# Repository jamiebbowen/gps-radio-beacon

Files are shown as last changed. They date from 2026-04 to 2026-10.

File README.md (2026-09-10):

# GPS Radio Beacon

A long-range rocket-tracking system: an airborne **transmitter** continuously
reports GPS position over LoRa, and a handheld **receiver** displays bearing,
distance, and altitude to help recover the rocket after landing.

Tested on a Mach-0.99 / 2 km AGL flight with a 37 dB link margin — see
[`docs/flight-analysis.md`](docs/flight-analysis.md) for post-flight tooling.

## System overview

```
+-------------------------+           LoRa 433 MHz          +-------------------------+
|       TRANSMITTER       |  - - - - - - - - - - - - - ->  |         RECEIVER        |
|  (flies with the rocket)|   ~15+ km LoS (SF10/62.5kHz)  |   (handheld ground)     |
+-------------------------+                                 +-------------------------+
  - ItsyBitsy M4 (SAMD51)                                     - STM32F401 Black Pill
  - u-blox GPS (UART)                                         - NEO-6M GPS (UART)
  - BNO085 IMU (I2C) - launch detect                          - BNO055 IMU (I2C) - compass
  - E22-400M33S LoRa (SPI)                                    - E22 LoRa (SPI)
  - Power: 3.3 V + LiPo                                       - SSD1309 OLED (I2C)
                                                              - microSD log (SPI, littlefs)
```

The transmitter runs a state machine (`PRE_LAUNCH` -> `LAUNCH` -> `POST_LAUNCH`
-> `BATTERY_SAVE`) that auto-adapts TX cadence based on IMU-detected liftoff.
The receiver logs every packet to SD card for post-flight analysis.

## Repository layout

```
.
|-- transmitter/
|   |-- firmware/            Arduino/C++ code for the ItsyBitsy M4
|   |                        (radio, GPS, IMU, beacon state machine)
|   `-- pcb/                 KiCad schematic + PCB design
|
|-- receiver/
|   |-- firmware/            Bare-metal STM32 HAL code
|   |                        (radio, GPS, compass, OLED, SD card, navigation UI)
|   `-- tools/
|       `-- analyze_flight.py  Post-flight log analyzer + KML/MP4 renderer
|
|-- tools/
|   |-- log_summary.py       Field-log health forensics (wedges, watchdogs,
|   |                          telemetry gaps) - run on a session directory
|   `-- lfs_extract/         Pull Lxxxxxxx.TXT logs off the littlefs SD image
|
|-- docs/                    Reference documentation (wiring, radio config,
|                            reliability, troubleshooting)
|   `-- archive/             Historical bug post-mortems and migration notes
|
`-- README.md                This file
```

## Quick start

### Transmitter (ItsyBitsy M4)

```bash
cd transmitter/firmware
make install-deps     # one-time: installs arduino-cli + Adafruit SAMD core
make compile
make flash            # flashes via /dev/ttyACM0 by default
make monitor          # optional: USB serial log
```

Edit `include/mpu_config.h` to set your amateur-radio callsign.

### Receiver (STM32F401)

```bash
cd receiver/firmware
make                  # builds bin/gps_radio_beacon_receiver.elf
# Flash with st-flash, OpenOCD, or DFU as appropriate for your toolchain
```

### Flight analysis

After a flight, pull the SD card from the receiver and extract the logs
(the card is littlefs, not FAT):

```bash
make extract DEV=/dev/sdX                        # -> flight_data/<timestamp>/
python3 tools/log_summary.py flight_data/<ts>/   # health audit in seconds
python3 receiver/tools/analyze_flight.py flight_data/<ts>/L0001.TXT
```

Options:

| Flag | Purpose |
|---|---|
| `--kml flight.kml` | Google-Earth replay with time-animated rocket track |
| `--mp4 flight.mp4` | Headless 3-D animated replay (matplotlib + ffmpeg) |
| `--duration 15` | Compress flight into N-second video |
| `--sensitivity -134` | Override receiver sensitivity for range prediction |

Prints altitude, velocity, slant range, RSSI/SNR trace, predicted max range,
and packet-continuity statistics. See
[`docs/flight-analysis.md`](docs/flight-analysis.md) for details.

## Documentation

Detailed reference docs live in [`docs/`](docs/):

- **Hardware wiring**: receiver and transmitter pin assignments
- **LoRa radio**: E22-400M33S configuration and link-budget notes
- **Launch detection**: BNO085 IMU threshold tuning
- **GPS watchdog**: automatic recovery from fix loss
- **Reliability**: signal-quality monitoring, staleness, validation
- **SD card troubleshooting**: diagnostics for the receiver logger
- **Flight analysis**: using `analyze_flight.py`

Post-mortems of specific bug fixes are preserved under
[`docs/archive/`](docs/archive/).

## License / legal

The LoRa link operates on the 433 MHz band. In the US this falls under the
amateur-radio 70 cm allocation; the beacon transmits its callsign every
few minutes for FCC compliance. **Check your local regulations and hold
an appropriate license before transmitting.**

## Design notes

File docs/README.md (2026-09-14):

# Documentation index

Reference docs for the GPS radio beacon. Each file is self-contained; links
between them are cross-referenced where relevant.

## Hardware / wiring

- [`hardware-receiver.md`](hardware-receiver.md) - STM32F401 Black Pill pin
  assignments, peripherals, power, and connector layout.
- [`hardware-transmitter.md`](hardware-transmitter.md) - ItsyBitsy M4 Express
  pin assignments for GPS, LoRa, IMU, and power.
- [`pin-comparison.md`](pin-comparison.md) - Side-by-side TX vs RX pin-map
  quick reference.

## Radio / RF

- [`lora-radio.md`](lora-radio.md) - E22-400M33S module configuration and
  the software conversion from the original simple 433 MHz modules.
- [`reliability.md`](reliability.md) - Consolidated reliability doc:
  transmitter data validation, receiver signal-quality monitoring, LoRa
  link budget, and regulatory notes.

## Sensors / subsystems

- [`launch-detection.md`](launch-detection.md) - BNO085 IMU-based launch
  detection: threshold, debounce, and tuning guidance.
- [`gps-watchdog.md`](gps-watchdog.md) - Automatic GPS recovery system for
  silent fix loss.

## Operations / troubleshooting

- [`launch-day.md`](launch-day.md) - Field runbook: pad workflow, flight,
  recovery walk, crowded channels, and post-flight log review.
- [`bench-checklist.md`](bench-checklist.md) - Hardware power-up checks
  after flashing and before launch weekends.
- [`sd-card-troubleshooting.md`](sd-card-troubleshooting.md) - Diagnostics
  for the receiver SD-card logger.
- [`flight-analysis.md`](flight-analysis.md) - Using
  `receiver/tools/analyze_flight.py` for post-flight stats, KML replay,
  and MP4 rendering.

## Archive

[`archive/`](archive/) holds historical material that is no longer part of
the "current truth" but is worth preserving for context:

- Bug post-mortems (`clock-analysis`, `magic-number-solution`, `sd-cmd0-fix`,
  `lora-timing-fix`, `pin-changes-summary`)
- Design history (`binary-packet-proposal` - since **adopted**; the current
  wire format is the binary typed packets described in
  `transmitter/firmware/include/rf_packet.h`)
- Documents superseded by the main README or by a consolidated doc in this
  folder (`complete-system-summary`, `migration-guide`, `port-summary`,
  `build-fix`, `upload-fix`, `e22-400m33s-wiring`)

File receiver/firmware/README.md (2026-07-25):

# GPS Radio Beacon Receiver Firmware

This firmware is designed for an STM32F401 microcontroller-based receiver that tracks the location of a transmitter using GPS coordinates.

## Hardware Components
- STM32F401 Microcontroller
- QMX588L Compass Module
- NEO6M GPS Module
- RXM-433-LR RF Receiver
- SSD1309 OLED Display

## Functionality
The system receives GPS coordinates from a remote transmitter via the RF receiver, compares them with the local GPS position, and uses the compass to determine the relative direction and distance to the transmitter. The information is displayed on the OLED screen.

## Display Information
- Direction (degrees off from straight ahead)
- Distance to transmitter (meters)
- Time since last received ping

## Project Structure
- `inc/` - Header files
- `src/` - Source files
- `lib/` - Vendored libraries (littlefs is tracked; STM32CubeF4 is not - see below)
- `Makefile` - Build configuration

## Building

Requires `arm-none-eabi-gcc` and a local copy of STM32CubeF4, which is too
large (1+ GB) to track in this repository. On a fresh clone, fetch it once:

```bash
git clone --depth 1 --branch v1.28.2 \
    https://github.com/STMicroelectronics/STM32CubeF4.git lib/STM32CubeF4
cd lib/STM32CubeF4
git submodule update --init --depth 1 \
    Drivers/STM32F4xx_HAL_Driver \
    Drivers/CMSIS/Device/ST/STM32F4xx
```

Then build with:

```bash
make
```

Output artifacts land in `bin/` (`.elf`, `.bin`, `.hex`). CI performs the
same steps (see `.github/workflows/ci.yml`).

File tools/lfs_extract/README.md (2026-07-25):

# `lfs_extract` — pull flight data off the LittleFS SD card

The receiver writes `L####.TXT`, `BEACON.TXT`, and `COMPCAL.BIN` to the SD
card using **LittleFS**, not FAT. That choice gives us real power-fail
safety (the card can never be corrupted by a mid-write reset), but it means
Linux / macOS / Windows can no longer mount the card directly.

`lfs_extract` solves the read-back side: it opens the card as a raw block
device, mounts the LittleFS image in user-space, and copies every file out
to a normal host directory.

## Build

```sh
make -C tools/lfs_extract
```

Produces a single binary, `tools/lfs_extract/lfs_extract`.

## Use

```sh
# Identify the SD card device with `lsblk` or `dmesg | tail` first.
sudo tools/lfs_extract/lfs_extract /dev/sdb ./flight_data_2026_04_20
```

Root (or `disk` group membership) is required because the tool reads the
raw block device, not a mounted filesystem.

Typical output:

```
Device: /dev/sdb
Size:   29.72 GiB (7789184 LFS blocks)

Extracting:
  /BEACON.TXT                   30 bytes
  /COMPCAL.BIN                  25 bytes
  /L0001.TXT                14623 bytes
  /L0002.TXT               912442 bytes

Summary:
  files copied : 4
  bytes copied : 927120
  card used    : 342 / 7789184 blocks (0.00 %)
  output dir   : ./flight_data_2026_04_20
```

## Related top-level targets

From the repo root:

```sh
# Build this tool:
make tools

# One-shot extract:
make extract DEV=/dev/sdb OUT=./flight_data

# Wipe and re-format the card to LittleFS on the host (skips the firmware
# auto-format path, useful when re-using a card between flights):
make format-card DEV=/dev/sdb
```

## Constraint: geometry must match the firmware

The on-card layout is defined in `receiver/firmware/src/lfs_sd_bd.c`:

| Parameter | Value  |
|---|---|
| Sector size | 512 B  |
| Block size  | 4096 B |
| Cache size  | 512 B  |
| Lookahead | 128 B  |

`lfs_extract.c` mirrors these constants. If you ever tune them on the
firmware side, update this file to match (and reformat existing cards).

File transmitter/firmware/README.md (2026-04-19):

# GPS Radio Beacon - ItsyBitsy M4 Express Port

Successfully ported from ATtiny412 to **Adafruit ItsyBitsy M4 Express** (SAMD51 ARM Cortex-M4 @ 120MHz)

## Hardware Configuration

### Pin Assignments
- **Pin 11**: Radio TX (bit-banged UART at 300 baud)
- **Pin 12**: Radio Enable/Disable
- **Pin 10**: Launch Detection Switch (active low with pull-up)
- **Pins 0/1**: GPS UART (Hardware Serial1, 115200 baud)

### Connections
```
ItsyBitsy M4          Component
-----------           ---------
Pin 11         --->   Radio TX Data In
Pin 12         --->   Radio Enable/PTT
Pin 10         --->   Launch Switch (to GND when launched)
Pin 0 (RX1)    <---   GPS TX
Pin 1 (TX1)    --->   GPS RX
GND            --->   Common Ground
USB/5V         --->   Power Input
```

## Software Architecture

### Arduino Framework
The firmware now uses the Arduino framework instead of bare-metal AVR:
- **Hardware Serial1**: GPS communication (no more bit-banging)
- **Arduino timing**: `millis()`, `delay()`, `delayMicroseconds()`
- **GPIO**: `pinMode()`, `digitalWrite()`, `digitalRead()`
- **No watchdog**: SAMD51 doesn't enable watchdog by default

### Build System
Uses `arduino-cli` for command-line compilation and upload:
- No Arduino IDE required
- Makefile-based workflow
- Cross-platform support

## Installation

### 1. Install Arduino CLI

```bash
# Linux/macOS
curl -fsSL https://raw.githubusercontent.com/arduino/arduino-cli/master/install.sh | sh
sudo mv bin/arduino-cli /usr/local/bin/

# Or download from: https://arduino.github.io/arduino-cli/
```

### 2. Install Board Support

```bash
make install-deps
```

This installs Adafruit SAMD board support package.

### 3. Connect ItsyBitsy M4

Plug in the ItsyBitsy M4 via USB. It should appear as `/dev/ttyACM0` (Linux) or similar.

## Building and Uploading

### Compile Only
```bash
make compile
```

### Upload to Board
```bash
make flash
# Or specify port:
make PORT=/dev/ttyACM1 flash
```

### Monitor Serial Output
```bash
make monitor
```

### Clean Build
```bash
make clean
```

## Configuration

### Callsign
Edit `include/mpu_config.h` (yes, kept the filename for compatibility):
```c
#define BEACON_CALLSIGN "KD0ABC"  // Change to your callsign
```

### Timing Modes
Edit `include/config.h`:
```c
#define TESTING_MODE 0  // 0 = production, 1 = testing
```

**Testing Mode** (fast intervals for bench testing):
- Pre-launch: 10s intervals
- Launch: continuous for 30s
- Post-launch: continuous for 30s
- Battery save: 30s intervals
- Callsign: every 30s

**Production Mode** (optimized for flight):
- Pre-launch: 30s intervals
- Launch: continuous for 5 minutes
- Post-launch: continuous for 10 minutes  
- Battery save: 60s intervals
- Callsign: every 5 minutes

## Packet Format

### GPS Data Packet
```
$$lat,lon,alt,sats$$CHKSUM
```
Example: `$$3953.40363,-10506.93605,1671.7,12$$2F`

- Coordinates in NMEA format (DDMM.MMMMM)
- Negative sign for South/West
- XOR checksum in hex
- 300 baud transmission

### Fast GPS Packet (during launch)
```
$$lat,lon,alt$$CHKSUM
```
Omits satellite count for faster transmission.

### Callsign Packet
```
KD0ABC
```
Transmitted every 5 minutes for FCC compliance.

## Advantages Over ATtiny412

### Performance
- **480x faster CPU**: 120MHz vs 20MHz
- **768x more RAM**: 192KB vs 256 bytes
- **98x more Flash**: 512KB vs 4KB
- **Hardware UART**: No bit-banging for GPS

### Features
- USB Serial for debugging (`Serial.begin(115200)`)
- Hardware floating-point unit
- DMA support (not used yet)
- Real-time clock (not used yet)
- No memory constraints - can add features easily

### Development
- Easier debugging via USB Serial
- Faster compile times
- Arduino ecosystem libraries available
- No fuse programming required

## Beacon State Machine

1. **PRE_LAUNCH**: Waiting on pad, 30s intervals
2. **LAUNCH**: Continuous transmission for 5 min (180s fast, then full)
3. **POST_LAUNCH**: Continuous transmission for next 10 min
4. **BATTERY_SAVE**: 60s intervals indefinitely

Launch detection triggers from ANY state.

## Troubleshooting

### Board Not Found
```bash
# List connected boards
arduino-cli board list

# Try different port
make PORT=/dev/ttyACM1 flash
```

### Compilation Errors
```bash
# Reinstall board support
arduino-cli core update-index
arduino-cli core install adafruit:samd
```

### GPS Not Working
- Check Serial1 connections (pins 0/1)
- GPS expects 115200 baud, 3.3V logic
- ItsyBitsy M4 is 3.3V compatible

### Radio Not Transmitting
- Check pin 11 for TX data (300 baud)
- Check pin 12 for enable signal
- Verify radio module power

## Development Notes

### File Structure
- `main.cpp`: Main program with state machine
- `gps.cpp`: GPS parsing (NMEA)
- `radio.cpp`: Bit-banged 300 baud UART
- `uart.cpp`: Hardware Serial wrapper
- `beacon.cpp`: Packet formatting
- `launch_detect.cpp`: Launch switch debouncing
- `include/`: Headers
- `gps_radio_beacon.ino`: Arduino sketch wrapper

### Adding Features
With 192KB RAM and 512KB Flash, you can easily add:
- SD card logging
- Additional sensors (accelerometer, barometer)
- Data buffering
- More complex telemetry
- GPS configuration via UBX protocol

### Debugging
Add to `setup()`:
```cpp
Serial.begin(115200);
Serial.println("GPS Beacon Started");
```

Then use `make monitor` or any serial terminal.

## License
GPL v3 - Amateur Radio Use

## Author
Ported to ItsyBitsy M4 Express by AI Assistant
Original ATtiny412 version by Jamie Bowen

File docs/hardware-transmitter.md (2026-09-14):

# GPS Radio Beacon Transmitter - Complete Pin Assignment List

## Adafruit ItsyBitsy M4 Express - All Pin Assignments

### Board: ItsyBitsy M4 Express
- **MCU:** SAMD51G19 (ARM Cortex-M4 @ 120MHz)
- **Flash:** 512KB
- **RAM:** 192KB
- **Voltage:** 3.3V logic (5V tolerant power input)

---

## Pin Assignments by Function

### 🛰️ GPS Module (u-blox MAX-M10S)

**UART Interface (Hardware Serial1)**

| ItsyBitsy Pin | Arduino Pin | Function | GPS Pin | Description |
|---|---|---|---|---|
| **RX (0)** | 0 | Serial1 RX | TX | GPS transmits NMEA sentences |
| **TX (1)** | 1 | Serial1 TX | RX | GPS receives commands (optional) |
| - | - | - | VCC | Power (3.3V) |
| - | - | - | GND | Ground |

**Configuration:**
- Baud rate: 9600
- Format: 8N1
- Sentences: GNRMC, GNGGA (configured by firmware)

---

### 📡 LoRa Module (E22-400M33S / SX1268)

**SPI Interface + Control Pins**

| ItsyBitsy Pin | Arduino Pin | Function | E22-400M33S Pin | Description |
|---|---|---|---|---|
| **MOSI** | MOSI | SPI MOSI | MOSI (17) | SPI Master Out |
| **MISO** | MISO | SPI MISO | MISO (16) | SPI Master In |
| **SCK** | SCK | SPI SCK | SCK (18) | SPI Clock |
| **5** | 5 | GPIO OUT | NSS (19) | Chip Select (active low) |
| **11** | 11 | GPIO OUT | NRST (15) | Reset (active low) |
| **6** | 6 | GPIO IN | BUSY (14) | Busy status indicator |
| **9** | 9 | GPIO INT | DIO1 (13) | Interrupt (TxDone/RxDone) |
| **12** | 12 | GPIO OUT | TXEN (7) | TX Enable (optional) |
| - | - | - | VCC (9, 10) | Power (3.3V or 5V) |
| - | - | - | GND | Ground |
| - | - | - | ANT (21) | **433MHz Antenna (REQUIRED)** |

**LoRa Configuration:**
- Frequency: **433.0 MHz** (ISM band; 8-channel plan 433.00-434.75 MHz)
- Bandwidth: **62.5 kHz** (narrow: +3 dB sensitivity, 2x airtime)
- Spreading Factor: **10** (SF10 - range-first; fused stream at ~0.8 Hz in flight)
- Coding Rate: **4/8**
- Sync Word: **0x12** (private network)
- TX Power: **22 dBm** (~158mW at 3.3V, ~2W at 5V)
- Preamble: **16 symbols** (TX) / 8 (RX is tolerant: longer only overlaps more)

**Notes:**
- Hardware SPI uses default ItsyBitsy M4 pins (MOSI, MISO, SCK)
- TXEN pin is optional and may not be used on all E22-400M33S variants
- Maximum range: ~15-20km line-of-sight at 22 dBm

---

### 🧭 IMU / Accelerometer (BNO085)

**I2C Interface**

| ItsyBitsy Pin | Arduino Pin | Function | BNO085 Pin | Description |
|---|---|---|---|---|
| **SDA** | SDA | I2C Data | SDA | I2C Data |
| **SCL** | SCL | I2C Clock | SCL | I2C Clock |
| **10** | 10 | GPIO OUT | RST | Reset (optional, can be -1) |
| - | - | - | VCC | Power (3.3V) |
| - | - | - | GND | Ground |

**I2C Configuration:**
- Address: **0x4A** (or 0x4B if SA0 pin is high)
- Clock speed: Standard I2C (100kHz or 400kHz)
- Purpose: Launch detection via acceleration sensing

**Launch Detection Settings:**
- Threshold: **20 m/s²** (~2g sustained acceleration)
- Duration: **100ms** minimum above threshold
- Settle time: **2000ms** after power-on before monitoring

---

### 💡 Status LED (Onboard)

| ItsyBitsy Pin | Arduino Pin | Function | Description |
|---|---|---|---|
| **13** | 13 / LED_BUILTIN | GPIO OUT | Red onboard LED |

**Usage:**
- Standard Arduino LED_BUILTIN
- Can be used for status indication
- Active HIGH

---

## ItsyBitsy M4 Complete Pinout

### Digital I/O Pins

| Physical Pin | Arduino Pin | Current Use | Available? | Notes |
|---|---|---|---|---|
| 0 (RX) | 0 | GPS RX | ❌ | Hardware Serial1 RX |
| 1 (TX) | 1 | GPS TX | ❌ | Hardware Serial1 TX |
| 2 | 2 | **Available** | ✅ | Digital I/O, PWM |
| 3 | 3 | **Available** | ✅ | Digital I/O, PWM |
| 4 | 4 | **Available** | ✅ | Digital I/O, PWM |
| 5 | 5 | LoRa CS | ❌ | SPI Chip Select |
| 7 | 7 | LoRa BUSY | ❌ | LoRa status (pin 6 does not exist on ItsyBitsy M4) |
| 9 | 9 | LoRa DIO1 | ❌ | LoRa interrupt |
| 10 | 10 | IMU Reset | ❌ | BNO085 reset (optional) |
| 11 | 11 | LoRa RESET | ❌ | LoRa reset |
| 12 | 12 | LoRa TXEN | ⚠️ | LoRa TX enable (optional) |
| 13 (LED) | 13 | Onboard LED | ⚠️ | Can be repurposed |
| SCK | SCK | LoRa SPI CLK | ❌ | Hardware SPI |
| MOSI | MOSI | LoRa SPI MOSI | ❌ | Hardware SPI |
| MISO | MISO | LoRa SPI MISO | ❌ | Hardware SPI |
| SCL | SCL | IMU I2C CLK | ❌ | Hardware I2C |
| SDA | SDA | IMU I2C DATA | ❌ | Hardware I2C |

### Analog Pins

| Physical Pin | Arduino Pin | Current Use | Available? | Notes |
|---|---|---|---|---|
| A0 | A0 | **Available** | ✅ | Analog input, 12-bit ADC |
| A1 | A1 | **Available** | ✅ | Analog input, 12-bit ADC |
| A2 | A2 | **Available** | ✅ | Analog input, 12-bit ADC |
| A3 | A3 | **Available** | ✅ | Analog input, 12-bit ADC |
| A4 | A4 | **Available** | ✅ | Analog input, 12-bit ADC |
| A5 | A5 | **Available** | ✅ | Analog input, 12-bit ADC |

**Note:** Analog pins can also be used as digital I/O

---

## Available Pins for Expansion (9 pins)

### Digital Pins Available:
- **Pin 2** - Digital I/O, PWM
- **Pin 3** - Digital I/O, PWM
- **Pin 4** - Digital I/O, PWM
- **Pin 7** - Digital I/O, PWM

### Analog Pins Available:
- **A0** - Analog/Digital, 12-bit ADC
- **A1** - Analog/Digital, 12-bit ADC
- **A2** - Analog/Digital, 12-bit ADC
- **A3** - Analog/Digital, 12-bit ADC
- **A4** - Analog/Digital, 12-bit ADC
- **A5** - Analog/Digital, 12-bit ADC

### Potentially Repurposable:
- **Pin 12** - TXEN (if not needed by your E22-400M33S variant)
- **Pin 13** - LED (if visual status not needed)

---

## Interface Summary

| Interface | Pins Used | Connected To | Notes |
|---|---|---|---|
| **Hardware SPI** | SCK, MOSI, MISO, Pin 5 (CS) | E22-400M33S LoRa | High-speed SPI |
| **Hardware I2C** | SDA, SCL | BNO085 IMU | Shared bus |
| **Hardware Serial1** | Pin 0 (RX), Pin 1 (TX) | GPS Module | 9600 baud UART |
| **GPIO** | Pins 6, 9, 10, 11, 12 | LoRa control, IMU reset | Digital I/O |

---

## Power Configuration

### Power Input Options:

1. **USB Power (5V)**
   - Connect via USB-C port
   - Onboard regulator provides 3.3V to board
   - Can power all peripherals

2. **Battery Power (3.7-6V)**
   - Connect to **BAT** pin (LiPo friendly)
   - Onboard charger for single-cell LiPo
   - Regulator provides 3.3V

3. **Regulated Power (3.3V)**
   - Connect directly to **3.3V** pin
   - Bypass onboard regulator
   - Use if you have external 3.3V supply

### Power Consumption Estimate:

| Component | Current Draw | Notes |
|---|---|---|
| SAMD51 MCU | ~30-50mA | Active @ 120MHz |
| GPS Module | ~40-60mA | Acquiring/tracking |
| LoRa (Standby) | ~2µA | Sleep mode |
| LoRa (RX) | ~14mA | Receive mode (not used often) |
| LoRa (TX @ 22dBm) | ~120mA @ 3.3V | During transmission |
| LoRa (TX @ 33dBm) | ~1200mA @ 5V | Maximum power (if 5V supply) |
| BNO085 IMU | ~10-15mA | Active sampling |
| **Total (typical)** | **~100-135mA** | Between transmissions |
| **Total (TX burst)** | **~220-285mA** | During transmission @ 3.3V |

### Battery Life Estimates:

**Pre-launch (30s intervals):**
- Average: ~110mA
- 1000mAh LiPo: ~9 hours
- 2000mAh LiPo: ~18 hours

**Launch/Recovery (continuous TX):**
- Average: ~250mA
- 1000mAh LiPo: ~4 hours
- 2000mAh LiPo: ~8 hours

**Battery Save (60s intervals):**
- Average: ~105mA
- 1000mAh LiPo: ~9.5 hours
- 2000mAh LiPo: ~19 hours

---

## Firmware Configuration

### Callsign
Set in `mpu_config.h`:
```cpp
#define BEACON_CALLSIGN "KE0MZS"  // Update with your callsign
```

### LoRa Parameters
Match these with receiver:
```cpp
#define LORA_FREQUENCY      433.0       // MHz
#define LORA_BANDWIDTH      62.5        // kHz (narrow, +3 dB)
#define LORA_SPREADING      10          // SF10 (range-first)
#define LORA_CODING_RATE    8           // 4/8 (edge-of-link margin)
#define LORA_SYNC_WORD      0x12        // Private
#define LORA_TX_POWER       22          // dBm chip drive (E22 PA output ~33 dBm)
```

### Launch Detection
```cpp
#define LAUNCH_ACCEL_THRESHOLD  20.0    // m/s² (~2g)
#define LAUNCH_ACCEL_DURATION   100     // ms
#define LAUNCH_SETTLE_TIME      2000    // ms
```

---

## Testing vs Production Mode

Set in `config.h`:
```cpp
#define TESTING_MODE 0  // 0 = Production, 1 = Testing
```

### Testing Mode (TESTING_MODE = 1):
- Pre-launch interval: **10 seconds**
- Launch duration: **30 seconds**
- Post-launch duration: **30 seconds**
- Battery save interval: **30 seconds**
- Debug output: **Enabled**

### Production Mode (TESTING_MODE = 0):
- Pre-launch interval: **30 seconds**
- Launch duration: **5 minutes**
- Post-launch duration: **10 minutes**
- Battery save interval: **60 seconds**
- Debug output: **Disabled**

---

## Beacon State Machine

```
┌──────────────┐
│  PRE_LAUNCH  │ ← Initial state
│  (30s TX)    │
└──────┬───────┘
       │ Launch detected (2g for 100ms)
       ↓
┌──────────────┐
│    LAUNCH    │
│ (Continuous) │ ← 5 minutes
└──────┬───────┘
       │ After 5 minutes
       ↓
┌──────────────┐
│ POST_LAUNCH  │
│ (Continuous) │ ← 10 minutes
└──────┬───────┘
       │ After 10 minutes
       ↓
┌──────────────┐
│ BATTERY_SAVE │
│  (60s TX)    │ ← Until battery dies
└──────────────┘
```

**Note:** Launch detection can trigger from ANY state!

---

## Packet Format

Transmitted packets use compact NMEA format:

### GPS Data Packet:
```
$$lat,lon,alt,sats,fix,launch_status,callsign$$CHKSUM
```

**Example:**
```
$$3953.40363,-10506.93605,1671.7,12,1,45,KE0MZS$$2F
```

Fields:
- `lat`: Latitude in NMEA format (DDMM.MMMMM)
- `lon`: Longitude in NMEA format (DDDMM.MMMMM)
- `alt`: Altitude in meters
- `sats`: Number of satellites
- `fix`: GPS fix quality (0=invalid, 1=GPS, 2=DGPS)
- `launch_status`: 
  - `N` = Not launched
  - `###` = Seconds since launch (e.g., `45` = 45 seconds ago)
- `callsign`: Ham radio callsign
- `CHKSUM`: XOR checksum (2 hex digits)

### Callsign Packet:
```
$$CALLSIGN$$
```

**Example:**
```
$$KE0MZS$$
```

Transmitted every 5 minutes for FCC compliance.

---

## Hardware Connections Diagram

```
┌────────────────────────────────┐
│   Adafruit ItsyBitsy M4        │
│   SAMD51 @ 120MHz              │
│                                │
│  RX(0) ◄──── TX        GPS     │
│  TX(1) ────► RX    MAX-M10S    │
│                                │
│  Pin 5 ────► NSS              │
│  Pin 11 ───► NRST             │
│  Pin 7 ◄──── BUSY   E22-400M33S│
│  Pin 9 ◄──── DIO1    LoRa      │
│  Pin 12 ───► TXEN   (SX1268)   │
│  SCK ──────► SCK               │
│  MOSI ─────► MOSI              │
│  MISO ◄──── MISO               │
│                      ANT ──🏁  │
│  SDA ◄────► SDA               │
│  SCL ─────► SCL     BNO085     │
│  Pin 10 ───► RST      IMU      │
│                                │
│  BAT ◄───── LiPo 3.7V          │
└────────────────────────────────┘
```

---

## Critical Notes

### ⚠️ Before Flight:

1. **Update Callsign**
   - Edit `BEACON_CALLSIGN` in `mpu_config.h`
   - Must be valid amateur radio callsign

2. **Antenna Connection**
   - **NEVER power on without antenna!**
   - Will damage LoRa module
   - Use proper 433MHz antenna

3. **Testing Mode**
   - Set `TESTING_MODE 0` for flight
   - Test on ground with `TESTING_MODE 1`

4. **GPS Lock**
   - Wait for GPS fix before flight
   - Needs clear sky view
   - Takes 30-60 seconds cold start

5. **Battery**
   - Use 1S LiPo (3.7V nominal)
   - Minimum 1000mAh recommended
   - 2000mAh for extended recovery

6. **IMU Calibration**
   - BNO085 auto-calibrates
   - Let sit still for 2 seconds after power-on
   - Avoid vibration during calibration

---

## Pin Usage Summary

- **Used Pins:** 13 (including SPI/I2C/UART hardware pins)
- **Available Pins:** 9 (4 digital + 6 analog, minus conflicts)
- **Potentially Repurposable:** 2 (TXEN, LED)

**Pin Utilization:** ~50% of available GPIO used

---

## Compatibility with Receiver

**Both transmitter and receiver must use identical LoRa settings:**

| Parameter | Value | Must Match |
|---|---|---|
| Frequency | 433.0 MHz | ✅ YES |
| Bandwidth | 62.5 kHz | ✅ YES |
| Spreading Factor | 10 | ✅ YES |
| Coding Rate | 4/8 | ✅ YES |
| Sync Word | 0x12 | ✅ YES |
| Packet Format | Binary typed packets V2 (GPS 14 B / fused 20 B / heartbeat 8 B; +rocket_id vs legacy V1 GPS 13 B / fused 19 B) | ✅ YES |

**TX Power does NOT need to match** (transmitter can use higher power)

---

## Document Information

**Version:** 1.0  
**Last Updated:** 2024-11-18  
**Compatible Firmware:** v2.0+ (LoRa E22-400M33S)  
**Board:** Adafruit ItsyBitsy M4 Express  
**Platform:** Arduino + PlatformIO

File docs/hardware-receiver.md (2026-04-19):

# GPS Radio Beacon Receiver - Complete Wiring Diagram

## STM32F401 Black Pill Pin Assignments

### Power
| Pin | Connection | Notes |
|-----|---|---|
| 3.3V | Power rail | Connect to all 3.3V devices |
| GND | Ground rail | Common ground for all components |
| 5V | USB power input | Optional - can power from USB or external |

---

## Component Connections

### 1. E22-400M33S LoRa Module (NEW!)

**SPI2 Interface + Control Pins**

STM32F4 → E22-400M33S
PB13 → SCK
PB14 → MISO
PB15 → MOSI
PB12 → CS
PA8  → RESET
PB0  → BUSY
PB1  → DIO1
3.3V → VCC
GND  → GND
     → ANT (433MHz antenna - REQUIRED!)

| STM32F4 Pin | Function | E22-400M33S Pin | Description |
|---|---|---|---|
| **PB13** | SPI2_SCK | SCK | SPI Clock |
| **PB14** | SPI2_MISO | MISO | SPI Master In Slave Out |
| **PB15** | SPI2_MOSI | MOSI | SPI Master Out Slave In |
| **PB12** | GPIO_OUT | NSS/CS | Chip Select (active low) |
| **PA8** | GPIO_OUT | NRST | Reset (active low) |
| **PB0** | GPIO_IN | BUSY | Busy status indicator |
| **PB1** | GPIO_INT | DIO1 | Interrupt (RX/TX done) |
| **3.3V** | Power | VCC | Power supply (3.3V only!) |
| **GND** | Ground | GND | Ground |
| - | - | **ANT** | **433MHz antenna (REQUIRED)** |

⚠️ **IMPORTANT:** 
- E22-400M33S operates at **3.3V only** - do NOT use 5V!
- **Antenna is mandatory** - transmitting without antenna will damage the module
- Use a 433MHz antenna (wire length ~17.3cm for 1/4 wave)

---

### 2. GPS Module (NEO-6M or similar)

**USART2 Interface**

| STM32F4 Pin | Function | GPS Pin | Description |
|---|---|---|---|
| **PA2** | USART2_TX | RX | GPS receives data (not used) |
| **PA3** | USART2_RX | TX | GPS transmits NMEA sentences |
| **3.3V** | Power | VCC | Power supply |
| **GND** | Ground | GND | Ground |

**Settings:**
- Baud rate: 9600 (configured in firmware)
- 8N1 (8 data bits, no parity, 1 stop bit)
- NMEA sentence output

---

### 3. BNO055 Compass/IMU Module

**I2C1 Interface (Shared with Display)**

| STM32F4 Pin | Function | BNO055 Pin | Description |
|---|---|---|---|
| **PB6** | I2C1_SCL | SCL | I2C Clock |
| **PB7** | I2C1_SDA | SDA | I2C Data |
| **3.3V** | Power | VIN/VCC | Power supply |
| **GND** | Ground | GND | Ground |

**I2C Address:** 0x28 (default, ADR pin low)  
**Alternative Address:** 0x29 (if ADR pin high)

---

### 4. SSD1309 OLED Display (128x64)

**I2C1 Interface (Shared with Compass)**

| STM32F4 Pin | Function | Display Pin | Description |
|---|---|---|---|
| **PB6** | I2C1_SCL | SCL | I2C Clock |
| **PB7** | I2C1_SDA | SDA | I2C Data |
| **3.3V** | Power | VCC | Power supply |
| **GND** | Ground | GND | Ground |

**I2C Address:** 0x3C  
**Resolution:** 128x64 pixels, monochrome

---

### 5. MicroSD Card Module

**SPI1 Interface**

| STM32F4 Pin | Function | SD Card Pin | Description |
|---|---|---|---|
| **PA5** | SPI1_SCK | SCK/CLK | SPI Clock |
| **PA6** | SPI1_MISO | MISO/DO | SPI Data Out |
| **PA7** | SPI1_MOSI | MOSI/DI | SPI Data In |
| **PA4** | GPIO_OUT | CS | Chip Select |
| **PB9** | GPIO_IN | CD/DETECT | Card detect (optional) |
| **3.3V** | Power | VCC | Power supply |
| **GND** | Ground | GND | Ground |

**Note:** Most SD card modules have onboard level shifters and regulators

---

### 6. Mode Button

**GPIO Input with Pull-up**

| STM32F4 Pin | Function | Button Connection |
|---|---|---|
| **PB10** | GPIO_IN_PULLUP | Button side 1 |
| **GND** | Ground | Button side 2 |

**Function:** Press to cycle through display modes

---

### 7. Status LED

**GPIO Output**

| STM32F4 Pin | Function | LED Connection |
|---|---|---|
| **PC13** | GPIO_OUT | LED Anode (+) |
| **GND** | Ground | LED Cathode (-) via resistor |

**Note:** STM32F4 Black Pill has onboard LED on PC13

---

## Complete Pin Mapping Summary

### Port A (GPIOA)
| Pin | Function | Connected To |
|-----|---|---|
| PA0 | Available | - |
| PA1 | Available | - |
| PA2 | USART2_TX | GPS RX |
| PA3 | USART2_RX | GPS TX |
| PA4 | SPI1_CS | SD Card CS |
| PA5 | SPI1_SCK | SD Card SCK |
| PA6 | SPI1_MISO | SD Card MISO |
| PA7 | SPI1_MOSI | SD Card MOSI |
| PA8 | GPIO_OUT | LoRa RESET |
| PA9 | Available | - |
| PA10 | Available | - |
| PA11 | USB D- | (USB if used) |
| PA12 | USB D+ | (USB if used) |
| PA13 | SWDIO | Debug/Programming |
| PA14 | SWCLK | Debug/Programming |
| PA15 | Available | - |

### Port B (GPIOB)
| Pin | Function | Connected To |
|-----|---|---|
| PB0 | GPIO_IN | LoRa BUSY |
| PB1 | GPIO_INT | LoRa DIO1 |
| PB2 | Available | - |
| PB3 | Available | - |
| PB4 | Available | - |
| PB5 | Available | - |
| PB6 | I2C1_SCL | Display & Compass SCL |
| PB7 | I2C1_SDA | Display & Compass SDA |
| PB8 | Available | - |
| PB9 | GPIO_IN | SD Card Detect |
| PB10 | GPIO_IN | Mode Button |
| PB11 | Available | - |
| PB12 | GPIO_OUT | LoRa CS |
| PB13 | SPI2_SCK | LoRa SCK |
| PB14 | SPI2_MISO | LoRa MISO |
| PB15 | SPI2_MOSI | LoRa MOSI |

### Port C (GPIOC)
| Pin | Function | Connected To |
|-----|---|---|
| PC13 | GPIO_OUT | Status LED |
| PC14 | Available | - |
| PC15 | Available | - |

---

## Pin Conflicts - RESOLVED ✅

All pin conflicts have been resolved in the latest firmware version:

### ✅ Fixed Issues:

1. **Button Pin Conflict** - RESOLVED
   - Button moved from PB12 → **PB10**
   - LoRa CS remains on **PB12**
   - No conflict!

2. **SD Card / LoRa Conflict** - RESOLVED
   - LoRa BUSY moved from PA7 → **PB0**
   - LoRa DIO1 moved from PA6 → **PB1**
   - SD Card MISO stays on **PA6**
   - SD Card MOSI stays on **PA7**
   - No conflict!

3. **SD Card Detect / LoRa Reset Conflict** - RESOLVED
   - SD Card Detect moved from PA8 → **PB9**
   - LoRa RESET stays on **PA8**
   - No conflict!

---

## Recommended Breadboard Layout

```
┌────────────────────────────────────────────┐
│  Power Rails                                │
│  ● 3.3V ════════════════════════════════   │
│  ● GND  ════════════════════════════════   │
└────────────────────────────────────────────┘

┌─────────────────┐  ┌──────────────┐
│   STM32F401     │  │ GPS Module   │
│   Black Pill    │  │   (NEO-6M)   │
│                 │  │              │
│  PA2 ─────────────► RX           │
│  PA3 ◄───────────── TX           │
│  3.3V ────────────► VCC          │
│  GND  ────────────► GND          │
└─────────────────┘  └──────────────┘

┌─────────────────┐  ┌──────────────┐
│   STM32F401     │  │ E22-400M33S  │
│   Black Pill    │  │ LoRa Module  │
│                 │  │              │
│  PB13 ────────────► SCK          │
│  PB14 ◄──────────── MISO         │
│  PB15 ────────────► MOSI         │
│  PB12 ────────────► CS/NSS       │
│  PA8  ────────────► NRST         │
│  PB0  ◄──────────── BUSY         │
│  PB1  ◄──────────── DIO1         │
│  3.3V ────────────► VCC          │
│  GND  ────────────► GND          │
│                 │  │ ANT ─── 🏁   │ (Antenna!)
└─────────────────┘  └──────────────┘

┌─────────────────┐  ┌──────────────┐  ┌──────────────┐
│   STM32F401     │  │   BNO055     │  │  SSD1309     │
│   Black Pill    │  │   Compass    │  │  Display     │
│                 │  │              │  │              │
│  PB6  ────────────►─┬─ SCL        │  │              │
│  PB7  ────────────►─┼─ SDA        │  │              │
│  3.3V ────────────►─┤              │  │              │
│  GND  ────────────►─┤              │  │              │
│                 │  └──────────────┘  │              │
│                 │                     │ SCL ◄────────┤
│                 │                     │ SDA ◄────────┤
│                 │                     │ VCC ◄────────┤
│                 │                     │ GND ◄────────┤
└─────────────────┘                     └──────────────┘

     [Button]
    ┌────┴────┐
    │         │
PB10 ●────────● GND
(Mode Button)
```

---

## Power Consumption Estimate

| Component | Current Draw | Notes |
|---|---|---|
| STM32F401 | ~30-50mA | Active mode @ 84MHz |
| GPS Module | ~40-60mA | Acquiring/tracking |
| LoRa (RX) | ~12-15mA | Receive mode |
| LoRa (TX) | ~120mA | During transmission (transmitter only) |
| BNO055 | ~12mA | Normal operation |
| OLED Display | ~20-30mA | Depending on pixels lit |
| SD Card | ~50-100mA | During write operations |
| **Total (typical)** | **~165-190mA** | Without SD writes |
| **Total (max)** | **~265-315mA** | With SD active |

**Recommended Battery:** 
- 3.7V LiPo, 1000-2000mAh for 3-6 hours operation
- Use voltage regulator for stable 3.3V

---

## Testing Procedure

### 1. Power-On Test
- [ ] Connect 3.3V and GND first
- [ ] Verify voltage on power rails with multimeter
- [ ] Check LED lights on PC13

### 2. Display Test
- [ ] OLED should display initialization
- [ ] Verify I2C communication (PB6/PB7)

### 3. GPS Test
- [ ] Place near window for GPS signal
- [ ] Watch for NMEA sentences on PA3
- [ ] Display should show GPS data within 30-60s

### 4. Compass Test
- [ ] BNO055 should calibrate automatically
- [ ] Rotate receiver and verify heading changes
- [ ] Check compass mode on display

### 5. LoRa Test
- [ ] Power on transmitter with LoRa
- [ ] Verify packet reception on receiver
- [ ] Check RSSI values (should be negative dBm)

### 6. SD Card Test
- [ ] Insert formatted SD card
- [ ] Verify data logging starts
- [ ] Check SD card mode shows storage info

### 7. Button Test
- [ ] Press button to cycle display modes
- [ ] Should see: GPS → RF → Compass Raw → Compass Diag → Heading → IMU → Navigation → SD Card

---

## Troubleshooting

### Display Not Working
- Check I2C connections (PB6/PB7)
- Verify 3.3V power to display
- Check I2C address (should be 0x3C)

### GPS No Data
- Ensure clear view of sky
- Check UART connections (PA2/PA3 might be swapped)
- Verify baud rate is 9600

### LoRa No Packets
- **Check antenna is connected!**
- Verify SPI connections (PB13/14/15)
- Check CS pin (PB12) not shorted to button
- Ensure transmitter is powered and configured

### Compass Not Responding
- Check I2C shared bus with display
- Verify BNO055 address (0x28 or 0x29)
- May need calibration (wave figure-8 motion)

### SD Card Not Detected
- Verify card is FAT32 formatted
- Check SPI connections (PA5/6/7)
- Try different SD card

---

## Safety Notes

⚡ **Electrical Safety**
- Never exceed 3.3V on any STM32 pin
- Double-check polarity before connecting power
- Use proper decoupling capacitors (0.1µF near each IC)

📡 **RF Safety**
- Always connect antenna before powering LoRa module
- 433MHz is legal for low-power use (check local regulations)
- Keep antenna away from body during transmission

🚀 **Rocketry Safety**
- Secure all connections with hot glue or tape
- Use proper strain relief on wires
- Test system thoroughly on ground before flight
- Consider backup power source for critical flights

---

## Firmware Flash Instructions

```bash
# Navigate to firmware directory
cd receiver/firmware

# Clean previous build
make clean

# Build firmware
make -j4

# Flash via DFU (STM32 in bootloader mode)
make flash

# Or flash via ST-Link
st-flash write bin/gps_radio_beacon_receiver.bin 0x8000000
```

---

## Component Sources

### Recommended Parts
- **STM32F401 Black Pill:** ~$4-6 on AliExpress/Amazon
- **E22-400M33S:** ~$8-12 on AliExpress (ensure 433MHz version)
- **NEO-6M GPS:** ~$6-10 with antenna
- **BNO055:** ~$15-25 (Adafruit breakout recommended)
- **SSD1309 OLED:** ~$5-8 (128x64, I2C)
- **MicroSD module:** ~$2-4
- **Antenna 433MHz:** ~$2-5 (or make 17.3cm wire dipole)

### Total Cost
**Approximately $50-80** for complete receiver build

---

**Document Version:** 1.0  
**Last Updated:** 2024-11-15  
**Compatible Firmware:** v2.0+ (with LoRa support)

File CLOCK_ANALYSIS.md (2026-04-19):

# STM32F4 Clock Analysis - Magic Number Explanation

## 🎯 ROOT CAUSE IDENTIFIED

The "magic numbers" are needed because of a **critical mismatch** between hardware and software configuration!

## The Problem

### Hardware Reality
- **Actual crystal on STM32F401 Black Pill: 25MHz**

### Software Configuration  
- **HSE_VALUE in stm32f4xx_hal_conf.h: 8MHz** ❌

```c
// From inc/stm32f4xx_hal_conf.h:32
#define HSE_VALUE    ((uint32_t)8000000)  // WRONG! Should be 25000000
```

### The Impact
```
Mismatch Ratio = Actual Crystal / HSE_VALUE
               = 25,000,000 / 8,000,000
               = 3.125× ✓
```

This is **exactly** the magic number ratio we see everywhere:
- GPS baud: 9600 / 3072 = 3.125× ✓
- SPI comment: "~3x faster" ≈ 3.125× ✓

## How It Works (Clock Configuration)

### What the Code Thinks (Based on HSE_VALUE = 8MHz)
```c
PLL input  = 8MHz / 25 (PLLM) = 320kHz
VCO        = 320kHz × 84 (PLLN) = 26.88MHz  
SYSCLK     = 26.88MHz / 2 (PLLP) = 13.44MHz
APB1       = 13.44MHz / 2 = 6.72MHz
APB2       = 13.44MHz / 4 = 3.36MHz
```

### What Actually Happens (With 25MHz Crystal)
```c
PLL input  = 25MHz / 25 (PLLM) = 1MHz
VCO        = 1MHz × 84 (PLLN) = 84MHz
SYSCLK     = 84MHz / 2 (PLLP) = 42MHz
APB1       = 42MHz / 2 = 21MHz  
APB2       = 42MHz / 4 = 10.5MHz
```

### With APB Peripheral Clock Doubling Rule
When APBx prescaler ≠ 1, peripheral clocks are automatically 2× the bus clock:

**Actual peripheral clocks:**
- USART2 (APB1): 2 × 21MHz = **42MHz**
- SPI1 (APB2): 2 × 10.5MHz = **21MHz**

**What HAL library thinks:**
- USART2: 2 × 6.72MHz = **13.44MHz**
- SPI1: 2 × 3.36MHz = **6.72MHz**

## The Magic Number Explained

### GPS UART Example (Target: 9600 baud)

**UART Baud Rate Formula:**
```
BaudRate = Peripheral_Clock / (16 × BRR)
```

**What we need:**
```
Actual peripheral clock = 42MHz
Target baud = 9600
BRR = 42,000,000 / (16 × 9600) = 273.4375
```

**What HAL library calculates:**
```
HAL thinks peripheral clock = 13.44MHz
To get BRR = 273.4375 with HAL's calculation:
  Required_Input_Baud = 13,440,000 / (16 × 273.4375)
  Required_Input_Baud = 3072 ✓
```

**Verification:**
```
GPS_UART_BAUD = 3072
HAL calculates: BRR = 13,440,000 / (16 × 3072) = 273.4375
Actual baud: 42,000,000 / (16 × 273.4375) = 9600 ✓ PERFECT!
```

## The Fix

### Option 1: Fix HSE_VALUE (Recommended)
```c
// In inc/stm32f4xx_hal_conf.h
#define HSE_VALUE    ((uint32_t)25000000)  // Correct for Black Pill
```

Then use normal values:
```c
#define GPS_UART_BAUD  9600   // Normal value!
```

### Option 2: Keep Magic Numbers (Current Approach)
Document why the magic numbers work:
```c
#define GPS_UART_BAUD  3072   // Magic: 9600 / 3.125 (HSE mismatch compensation)
```

## Summary

| Parameter | What HAL Thinks | Actual Hardware | Ratio |
|---|---|---|---|
| HSE Crystal | 8 MHz | 25 MHz | 3.125× |
| System Clock | 13.44 MHz | 42 MHz | 3.125× |
| APB1 Clock | 6.72 MHz | 21 MHz | 3.125× |
| USART2 Clock | 13.44 MHz | 42 MHz | 3.125× |
| GPS Baud Input | 3072 | 9600 (effective) | 3.125× |

## Recommendation

**Fix the HSE_VALUE to match your hardware!** This will eliminate all magic numbers and make the code much clearer and more maintainable.

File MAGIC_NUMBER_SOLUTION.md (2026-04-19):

# Magic Numbers - Root Cause & Solution

## 🔍 The Mystery Solved

Your "magic numbers" exist because of a single configuration error:

```c
// inc/stm32f4xx_hal_conf.h line 32:
#define HSE_VALUE    ((uint32_t)8000000)   // ❌ WRONG!

// Should be:
#define HSE_VALUE    ((uint32_t)25000000)  // ✅ Correct for STM32F401 Black Pill
```

## 🧮 The Math

```
Mismatch Ratio = 25 MHz (actual) / 8 MHz (configured) = 3.125×
```

Every clock in your system is running 3.125× faster than the HAL library thinks!

## 📊 Evidence

All your magic numbers are exactly this ratio:

| Setting | Normal Value | Your Magic Value | Ratio |
|---|---|---|---|
| GPS UART Baud | 9600 | 3072 | 3.125× |
| System thinks | 13.44 MHz | Actually 42 MHz | 3.125× |
| APB1 thinks | 6.72 MHz | Actually 21 MHz | 3.125× |
| Comment says | "~3x faster" | - | ≈3.125× |

## 🔧 The Fix

### Simple Fix (Recommended)
Change one line in `receiver/firmware/inc/stm32f4xx_hal_conf.h`:

```c
// Line 32 - Change from:
#define HSE_VALUE    ((uint32_t)8000000)

// To:
#define HSE_VALUE    ((uint32_t)25000000)
```

Then update your constants to normal values:

```c
// In receiver/firmware/src/gps.c:
#define GPS_UART_BAUD    9600    // Was 3072

// In receiver/firmware/src/main.c:
hspi1.Init.BaudRatePrescaler = SPI_BAUDRATEPRESCALER_4;  // Was 16
```

### Benefits
- ✅ No more magic numbers
- ✅ Code matches hardware
- ✅ SystemCoreClock variable will be correct
- ✅ Timing delays will be accurate
- ✅ Future modifications won't need compensation

## 🎯 Why This Happened

STM32 Nucleo boards (the HAL default) use **8MHz** crystals.
STM32F401 Black Pill boards use **25MHz** crystals.

The default `stm32f4xx_hal_conf.h` assumes Nucleo hardware!

## ⚠️ Current System State

**Right now your system works because:**
1. PLL multiplies the wrong base frequency by the right amount
2. You compensate with magic numbers
3. Everything cancels out by coincidence

**But:**
- `SystemCoreClock` variable shows wrong value (13.44 MHz instead of 42 MHz)
- Any code using `SystemCoreClock` for timing will be wrong
- HAL_Delay() might be inaccurate
- Future peripherals will need new magic numbers

## 📝 Test After Fix

After changing HSE_VALUE, verify with oscilloscope:
1. GPS TX should show clean 9600 baud
2. System should still work identically
3. Magic numbers eliminated!

## 🚀 Next Steps

1. Back up your current working firmware
2. Change `HSE_VALUE` to 25000000
3. Update GPS_UART_BAUD to 9600
4. Update SPI prescaler to 4
5. Rebuild and test
6. Enjoy normal, non-magic code! ✨

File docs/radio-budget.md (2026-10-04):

# Radio data budget and phases

A reference for anyone flashing between bench and flight. All values are at
the flight profile: SF10 / BW 62.5 kHz / CR 4/8 / LDRO enabled / preamble 8 /
sync 0x12. Transmit airtime is the expense; the receiver idles otherwise.

Airtime per packet type at this configuration:

| Packet | Bytes | Airtime |
|---|---|---|
| TX fused position+velocity | 20  | ~1.00 s |
| TX inertial trace (IMU) | 20  | ~1.00 s |
| TX raw GPS (binary) | 14  | ~0.75 s |
| TX heartbeat | 9  | ~0.55 s |
| TX callsign (text) |  <16  | <0.85 s |
| TX launch T0 | 6  | ~0.42 s |
| RX->TX command reply | 6  | ~0.42 s |

Duty budget: we soften above ~85 % PA on-time per second; above that the
E22's regulator overheats during extended burns.

## Phase-by-phase policy (transmitter/firmware/flight_cadence.cpp)

Principles: the packet types you can afford are the ones that answer the
question that phase actually leaves you asking. The single FPGA-style
constraint: if something dies mid-phase, we want enough in RF to tell WHAT
died first.

| Phase | PQuestions to answer | Packets on the air |
|---|---|---|
| PRE_LAUNCH (pad) | Satellite health, link margin, callsign | Fused every 5 s + GPS every 5 s + heartbeat if no fix + callsign every 5 min. Idle budget is essentially free - we're waiting for lift. |
| LAUNCH (boost) | velocity/alt thrust curve, accel axes, T0 instant | fused @1.5 s + IMU @2 s, GPS silenced. (Post L0016 lesson.) At most ~90% duty for *shortest* window of the flight. |
| POST_LAUNCH (coast-apogee-under-chute) | when and where the chutes are, ballistic drift, velocity peak, apogee T | fused @1.5 s, IMU @2 s, GPS stays silenced. Recommended where forensics live past the shred-point. |
| LANDED | touchdown anchor + drag events | drop to BATTERY_SAVE: fused @60 s + GPS @60 s and keep alive |
| WALK/RECOVERY | last-remembered point, foul antenna margins | battery-save stays; stay-tx is the cheap version |

## Two-way channel (RX→TX)

Intent: post-landing v2 board: receiver asks probe command replies (e.g.,
MAC ping / CNR-verified response) with tiny 6-14 byte packets that the
receiver hears; the beacon never busy-listens: it limits received to the
2 quiet seconds along the cadence (combined with duty).

Wire contract (wire-boundary-stable):

| Packet | Type | Dir | Bytes | Purpose |
|---|---|---|---|---|
| CMD | 0x08 | RX → TX | 6 | { type, rocket_id, cmd_code, seq_hi, seq_lo } |
| ACK | 0x09 | TX → RX | 6 | { type, rocket_id, cmd_code, seq_hi, LSB } |

cmd_code reserves: 0x01=PING, 0x02=TUNE_CH (next channel hops together), rest
reserved. Both sides may drop a request if in flight: ACKs are best-effort.

Implementation status: see repository tags starting
*gently-seeded*; radios support it in software, but only scantly tested.

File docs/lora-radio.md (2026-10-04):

# E22-400M33S LoRa Module Conversion

## Overview
Successfully converted the GPS radio beacon receiver from UART-based RF (RXM-433-LR) to E22-400M33S LoRa module (SX1268 chipset). The transmitter was already using the E22-400M33S module.

## Changes Made

### 1. Created LoRa Driver (`lora.h` / `lora.c`)
- Complete SX1268 driver for STM32F4
- SPI-based communication
- Implements LoRa packet TX/RX
- Automatic receive mode
- RSSI and SNR measurement
- IRQ-based packet detection

### 2. Updated RF Receiver (`rf_receiver.c`)
- Replaced UART initialization with SPI initialization
- Changed from interrupt-driven UART to DIO1-interrupt-driven LoRa packet reception (EXTI on DIO1 sets a flag; the main loop drains the packet over SPI)
- Packet format at the time of conversion was `$$data$$CHKSUM`; the current
  firmware uses binary typed packets (see `transmitter/firmware/include/rf_packet.h`)

### 3. Removed UART Dependencies
- Removed `RF_Receiver_UART_RxCpltCallback()` from gps.c
- Deprecated UART calibration functions (kept for compatibility)

### 4. Updated Build System
- Added `lora.c` to Makefile
- All files compile successfully

## Hardware Connections

### STM32F4 Black Pill → E22-400M33S LoRa Module

| STM32F4 Pin | Function | E22-400M33S Pin | Description |
|---|---|---|---|
| PB13 | SPI2_SCK | SCK | SPI Clock |
| PB14 | SPI2_MISO| MISO | SPI Data Out |
| PB15 | SPI2_MOSI| MOSI | SPI Data In |
| PB12 | GPIO | NSS/CS | Chip Select |
| PA8 | GPIO | NRST | Reset (active low) |
| PB0 | GPIO | BUSY | Busy status (moved from PA7: SD conflict) |
| PB1 | GPIO_INT | DIO1 | Interrupt (RX/TX done) (moved from PA6: SD conflict) |
| PA9 | GPIO | RXEN | RF switch RX enable |
| 3.3V | Power | VCC | Power supply |
| GND | Ground | GND | Ground |

**Important Notes:**
- E22-400M33S operates at 3.3V - do not use 5V
- Antenna must be connected to ANT pin
- DIO1 is configured for interrupt on rising edge

## LoRa Configuration

Both transmitter and receiver use identical settings:

| Parameter | Value | Description |
|---|---|---|
| Frequency | 433.0 MHz | ISM band (8-channel plan, 433.00-434.75 MHz) |
| Bandwidth | 62.5 kHz | Narrow: +3 dB sensitivity, ~1.0 s/fused packet (20 B), LDRO on |
| Spreading Factor | 10 | SF10 (range over airtime) |
| Coding Rate | 4/8 | Forward error correction (+1 dB class margin, +18% airtime) |
| Sync Word | 0x12 | Private network; RX programs it explicitly (reg 0x0740 = `14 24`) |
| TX Power | 22 dBm | SX1268 chip output, which is exactly what drives the M33S's internal PA to its rated 33 dBm / 2W (verified module variant; chip drive past ~20 dBm only grows harmonics) |
| Preamble Length | 8 symbols | Standard; CAD+62 s re-acquire dwell cover lock robustness |
| CRC | Enabled | Packet integrity check |

Receiver-specific radio tuning (lora.c): boosted RX gain (reg 0x08AC = 0x96,
~+3 dB vs default power-saving) and band-specific image calibration for
430-440 MHz (CalibrateImage 0x6B/0x6F). Both were missing until the 2026-09
range investigation and matter most at the marginal end of the link.

Transmitter-specific tuning (radio.cpp): the PA over-current protection
(LORA_TX_CURRENT_MA = 140 mA) must be raised after radio.begin() - both the
chip reset default and RadioLib's begin() leave it at 60 mA, which clamps
every 22 dBm burst mid-packet. Note the current budget consequence: at full
PA drive the module can pull on the order of 1 A per packet; the ItsyBitsy
M4's 600 mA 3.3 V rail should be checked for droop under TX before flight
(scope or brown-out counter), or the module given its own heftier supply.

## Packet Format

The packet format remains unchanged from the previous implementation:

### GPS Data Packet
```
$$lat,lon,alt,sats,fix,launch,callsign$$CHKSUM
```
Example: `$$3953.40363,-10506.93605,1671.7,12,1,45,KE0MZS$$2F`

### Callsign Packet
```
$$CALLSIGN$$
```
Example: `$$KE0MZS$$`

## Testing Checklist

Before deploying, verify:

- [ ] LoRa module properly connected (check pin connections)
- [ ] Antenna connected to E22-400M33S ANT pin
- [ ] Firmware flashes successfully
- [ ] RF display mode shows packet reception
- [ ] RSSI and SNR values displayed
- [ ] GPS data correctly parsed from LoRa packets
- [ ] Navigation mode works with LoRa-received coordinates

## Expected Performance

### Range Expectations
- **Previous (300 baud UART):** ~500m line-of-sight
- **LoRa SF10/CR4-8/BW62.5k @ 433MHz, boosted RX gain:** datasheet floor ~-134 dBm; real-world
  range depends mostly on antenna installation and the receiver-side noise
  floor (park walk tests 2026-09: ~2.8 km through trees at ~6 dB above the
  local -70 dBm ambient floor)

### Link Budget
- TX Power: +22 dBm (chip max; module PA not driven)
- RX Sensitivity (SF10, BW62.5, CR4/8): ~-133 dBm datasheet, before local noise floor
- Link Budget: ~150 dB on paper; in practice capped by the RX ambient floor

### Data Rate
- SF10/CR4-8 @ 62.5kHz: ~0.49 kbps effective (20-byte fused packet ~1.0 s airtime)
- Flight phase (LAUNCH/POST_LAUNCH) streams **fused position + inertial
  trace** only: fused every 1.5 s, IMU-trace interleaves at 2 s. The raw
  GPS stream is parked for those two states - during flight every byte that
  isn't position owes a forensic answer.
- A `LAUNCH T0` packet fires once at the instant of detection (uptime +
  GPS fix age), stamped even if the link dies milliseconds later.
- Much better edge-of-range behavior than previous 300 baud implementation

### Beacon onboard flight log (post-shred forensics)
- The beacon itself now records scoped IMU + GPS + event rows into the
  SAMD51's unused internal flash pages (256 KB carved at 0x00040000).
  Arm: any launch-detect confirmation (~250 ms erases, radio-quiet already).
  Dump: plug USB with the beacon alive after recovery, the Serial monitor
  prints CSV on the console when told 'DUMP' (see boot banner).

## Benefits of LoRa

1. **Better Range:** 5-10x improvement over simple OOK modulation
2. **Noise Immunity:** Spread spectrum is very resistant to interference
3. **Lower Power:** More efficient than continuous transmission
4. **RSSI/SNR:** Real-time link quality metrics
5. **CRC Validation:** Built-in packet integrity checking

## Troubleshooting

### No Packets Received
1. Check SPI connections (MOSI/MISO/SCK/CS)
2. Verify BUSY pin not stuck high
3. Ensure both radios use same frequency/SF/BW
4. Check antenna connections on both ends

### Poor RSSI
1. Check antenna connections
2. Verify antenna is appropriate for 433 MHz
3. Ensure line-of-sight or minimal obstructions
4. Check for local interference (WiFi, etc.)

### Packet Errors
1. Monitor CRC error count
2. Check for frequency offset
3. Verify transmitter/receiver settings match
4. Consider reducing bandwidth or increasing SF for longer range

## Files Modified

### New Files
- `receiver/firmware/inc/lora.h` - LoRa driver header
- `receiver/firmware/src/lora.c` - LoRa driver implementation

### Modified Files
- `receiver/firmware/src/rf_receiver.c` - Switched to LoRa
- `receiver/firmware/inc/rf_receiver.h` - Updated header comments
- `receiver/firmware/src/gps.c` - Removed RF UART callback
- `receiver/firmware/Makefile` - Added lora.c to build
- `LORA_CONVERSION.md` - This documentation

## Build Status
✅ Firmware compiles successfully
✅ No undefined references
✅ Binary size: 73,760 bytes text + 568 bytes data + 7,096 bytes BSS = 81,424 bytes total

## Next Steps

1. Flash updated firmware to STM32F4
2. Connect E22-400M33S module per pin mapping above
3. Power on and verify LoRa initialization on display
4. Test packet reception from transmitter
5. Verify GPS parsing and navigation modes
6. Field test for range performance

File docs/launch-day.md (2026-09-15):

# Launch Day Runbook

Field sequence, built around what the receiver actually shows. Assumes the
bench checklist (`bench-checklist.md`) passed this weekend.

## Arriving at the site

1. **Power the receiver.** Watch boot: RF init OK, SD ready, compass
   calibration restored. Last Beacon position showing is fine (it's the
   previous flight's, loaded from the card) - unless the arrow points at
   another state (see cross-state sanity below).
2. **Watch the boot NF sweep.** The receiver sweeps all 8 channels at boot
   and logs them. `-70 dBm` on some channel = that channel is hot on this
   day; cleanest channels hover around `-80`. If you must pick (see
   "Crowded channel"), pick from the quietest ones, don't just flip a coin.

### Magnetic declination

The BNO055 measures *magnetic* north; the arrow points along *true* north.
The receiver now self-corrects: after your local GPS first fixes, the
CONUS declination grid gives the site value (Denver +8.5 deg, mid-Nevada
+11.9 deg, ...) and applies it once. An explicit `DECLIN.TXT` on the card
(produced by the user) still beats the table.

### Cross-state boot sanity

If the card's saved last-beacon position is more than ~100 km from where
the receiver's own GPS says YOU are (the normal "drove to another state"
case), the saved anchor is discarded on boot: the arrow would otherwise
point at last-flight landing coordinates, which is wrong and dangerous
now. The display drops to "no target" until fresh link data arrives.
No action needed; just know it can take a boot or two for RF position rows
to repopulate the target.
2. **RF stats page** (button-cycle): note `Bnd:` — should be `Bnd:--`
   after a cold boot. If it already shows an ID and rows of `FGN:` counts,
   you're hearing someone else's beacon; that's fine, see *Crowded channel*
   below.

## On the pad, before arming

3. Power/arm the beacon. Within ~30 s the receiver locks its channel and
   shows the callsign `KE0MZS-<id> CH<n>` (RF mode). Confirm `<id>` and
   `<n>` match the labels on the airframe and the jumper you mean to fly.
4. **PRE-FLIGHT page** — every row means something you can fix now:
   - `TX LINK WEAK xx dBm` → antenna/IPEX problem: fix before flight.
     (A healthy beacon on the rail is way above -75 dBm.)
   - `TST *KE0MZS-3 CH0*` → the beacon's callsign, starred - it was flashed
     with a TESTING_MODE build (30 s ID cadence). Reflash production before
     the pad unless you did that deliberately. The RF mode page stars the
     callsign the same way.
   - `TX GPS ACQ n sat` → normal cold start, wait; sats climbing = healthy.
   - `TX GPS CHK wiring!` / `CHK garbled` → GPS UART fault; open the rocket.
   - `TX IMU CHK dead!` → advisory only; the flight still works on GPS
     with the altitude-climb fallback, but you'll lose fused smoothing.
   - `PWR LOW 3.1xV` → the receiver's own supply is sagging (this is the
     exact brown-out scenario that cost us a session once). SWAP THE PACK
     BEFORE FLYING. `READY TO FLY` is blocked while the rail is low.
   - `COMPASS OK 3.3V` → rail healthy, the voltage reads with the name.
   - Wait for `** READY TO FLY **`.
5. Quick arrow sanity: walk 10 m away, arrow should track the pad.

## Flight

6. Watch the nav page: `Pkts:` counter climbing, `B:3D`, speed live.
   The row-5 range countdown reads like a fuel gauge for the link —
   when it approaches zero, expect dropouts.
7. Dropouts during boost/flip are normal. The arrow/Dist keep pointing at
   the last good fix; `Last:` age tells you how stale that is.

## Recovery

8. On `LANDED` (row 7 chip), the position is the touchdown anchor. Row 5
   becomes recovery intel:
   - `LANDED` — down, holding position, walk on.
   - `MOVED +Nm!` — it dragged after touchdown (wind/slope): what you're
     walking to is moving; keep an eye out visually.
   - `CLS N m/m` — closing rate. `AWY N m/m` — you're walking away from it
     (normal on road/terrain detours; it should flip back when you head in).
9. Over a hill we lose it entirely: `Last:` age just climbs — the arrow
   still points to the last known spot, which is where you should walk.
   Past ~5 minutes of silence the receiver re-scans for the beacon on its
   own; when you crest the rise and packets return, the position snaps to
   current.
10. If the beacon's GPS dies under cover (heartbeat-only: `HB R<id>` with
    sats low), the position also stays at last-known — walk it, then use
    eyes and the RF strength trend.

## Crowded channel (someone else on our frequency)

11. `FGN:` counters on RF stats mean foreign packets are being dropped —
    your position is protected by the airframe binding. If *you* become
    the foreign rocket (two airframes, one receiver, channel shared), the
    receiver lets go after ~20 min of only-foreign traffic and adopts the
    live one; to force it sooner, just step the channel manually.

## After recovery

12. Power the beacon down, then read the receiver log:
    - `RX FAULT...` rows on boot = last-boot crash dumps (PC/LR/registers);
      pair the PC against `gps_radio_beacon_receiver.elf` to locate the trap.
    - `TX reset: uptime N -> M cause=...` rows tell you what reset the beacon
      took (POR = fresh battery, WDT = firmware hang, BOD = rail dip).
    - `SD bus stepped down ...` = write trouble detected and bus slowed.
    - `TX reset` count + `RF wedge` count in `tools/log_summary.py <card>`
      remains the headline scorecard; anything non-OK there is a
      hardware report card, not noise.
13. Your own walk is logged too: the receiver writes its own GPS as BASE
    rows every 30 s (including through beacon blackouts). `analyze_flight.py
    --kml` now overlays the operator track on the flight replay, so you can
    see where contact was lost and regained relative to terrain - that is
    the raw material for tuning antenna placement and the re-acquire dwell.
14. Reusing the SD card between launches is now a tested path: boot appends
    a new `L####.TXT` (skipping existing ones) instead of formatting.
    `BEACON.TXT` / `QLOCK.BIN` / `COMPCAL.BIN` persist across sessions by
    design. No field format needed - just extract (`make extract DEV=...`)
    and hand the card back to the beacon, or keep the card seated and live
    in one long history.

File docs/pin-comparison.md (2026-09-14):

# Transmitter vs Receiver - Pin Comparison

## Quick Reference: Side-by-Side Comparison

---

## LoRa Module Connections

### E22-400M33S (SX1268) - Both Systems

| Function | **Transmitter** (ItsyBitsy M4) | **Receiver** (STM32F4 Black Pill) |
|---|---|---|
| **SPI SCK** | SCK (hardware SPI) | PB13 (SPI2_SCK) |
| **SPI MISO** | MISO (hardware SPI) | PB14 (SPI2_MISO) |
| **SPI MOSI** | MOSI (hardware SPI) | PB15 (SPI2_MOSI) |
| **CS/NSS** | Pin 5 | PB12 |
| **RESET** | Pin 11 | PA8 |
| **BUSY** | Pin 6 | PB0 |
| **DIO1** | Pin 9 | PB1 |
| **TXEN** | Pin 12 (optional) | Not used |
| **Power** | 3.3V or 5V | 3.3V |
| **Antenna** | 433MHz (IPEX/stamp) | 433MHz (wire/IPEX) |

---

## GPS Module Connections

### NEO-6M or Similar

| Function | **Transmitter** (ItsyBitsy M4) | **Receiver** (STM32F4 Black Pill) |
|---|---|---|
| **GPS TX** | Pin 0 (Serial1 RX) | PA3 (USART2_RX) |
| **GPS RX** | Pin 1 (Serial1 TX) | PA2 (USART2_TX) |
| **Baud Rate** | 9600 | 9600 |
| **Power** | 3.3V | 3.3V |

---

## IMU / Compass Connections

| Function | **Transmitter** (ItsyBitsy M4) | **Receiver** (STM32F4 Black Pill) |
|---|---|---|
| **Sensor** | BNO085 (IMU) | BNO055 (Compass/IMU) |
| **Purpose** | Launch detection | Heading/orientation |
| **SDA** | SDA (hardware I2C) | PB7 (I2C1_SDA) |
| **SCL** | SCL (hardware I2C) | PB6 (I2C1_SCL) |
| **RESET** | Pin 10 | Not used |
| **I2C Address** | 0x4A (BNO085) | 0x28 (BNO055) |
| **Power** | 3.3V | 3.3V |

---

## Additional Peripherals

### Transmitter Only:
- **None** - Transmitter is minimal (GPS + LoRa + IMU)

### Receiver Only:

| Peripheral | Pins | Description |
|---|---|---|
| **SSD1309 Display** | PB6 (SCL), PB7 (SDA) | 128x64 OLED, I2C @ 0x3C |
| **SD Card** | PA4 (CS), PA5 (SCK), PA6 (MISO), PA7 (MOSI), PB9 (Detect) | SPI1, data logging |
| **Mode Button** | PB10 | Cycle display modes |
| **Status LED** | PC13 | Onboard LED |

---

## LoRa Configuration - MUST MATCH!

| Parameter | Transmitter | Receiver | Match? |
|---|---|---|---|
| **Frequency** | 433.0 MHz | 433.0 MHz | ✅ |
| **Bandwidth** | 62.5 kHz | 62.5 kHz | ✅ |
| **Spreading Factor** | 10 (SF10) | 10 (SF10) | ✅ |
| **Coding Rate** | 4/8 | 4/8 | ✅ |
| **Sync Word** | 0x12 | 0x12 | ✅ |
| **TX Power** | 22 dBm | 22 dBm | ℹ️ Doesn't need to match |
| **Preamble** | 16 | 8 | ✅ Longer TX preamble only overlaps more |

---

## System Comparison

### Hardware Platforms

| Feature | **Transmitter** | **Receiver** |
|---|---|---|
| **Board** | Adafruit ItsyBitsy M4 Express | STM32F4 Black Pill |
| **MCU** | SAMD51G19 (ARM Cortex-M4) | STM32F401CCU6 (ARM Cortex-M4) |
| **Clock Speed** | 120 MHz | 84 MHz |
| **Flash** | 512 KB | 256 KB |
| **RAM** | 192 KB | 64 KB |
| **Logic Level** | 3.3V | 3.3V |
| **Power Input** | 3.3V - 6V (USB/BAT) | 3.3V or 5V (USB) |

### Power Consumption

| State | **Transmitter** | **Receiver** |
|---|---|---|
| **Idle** | ~100-135mA | ~165-190mA |
| **TX Active** | ~220-285mA @ 3.3V | ~120mA @ 3.3V (rarely transmits) |
| **TX Max Power** | ~1200mA @ 5V (33 dBm) | N/A (receiver doesn't TX often) |

### Battery Life (1000mAh LiPo)

| Mode | **Transmitter** | **Receiver** |
|---|---|---|
| **Standby** | ~9 hours (30s intervals) | ~5 hours (continuous) |
| **Active** | ~4 hours (continuous TX) | ~5 hours (continuous RX) |

---

## Firmware Differences

### Transmitter Features:
- ✅ GPS data acquisition
- ✅ LoRa transmission (continuous or periodic)
- ✅ Launch detection (BNO085 accelerometer)
- ✅ State machine (Pre-launch → Launch → Post-launch → Battery save)
- ✅ Callsign transmission (FCC compliance)
- ❌ No display
- ❌ No user input
- ❌ No data logging

### Receiver Features:
- ✅ GPS data acquisition (local position)
- ✅ LoRa reception (remote position from transmitter)
- ✅ Display modes (GPS, RF, Compass, Navigation, etc.)
- ✅ Compass/heading (BNO055)
- ✅ SD card data logging
- ✅ User input (mode button)
- ✅ Distance/bearing calculations
- ❌ No launch detection
- ❌ Minimal transmission (mostly RX)

---

## Available Pins

### Transmitter (ItsyBitsy M4):
- **Digital:** Pins 2, 3, 4, 7 (4 pins)
- **Analog:** A0-A5 (6 pins, can be digital too)
- **Total Available:** 10 pins

### Receiver (STM32F4):
- **Port A:** PA0, PA1, PA9, PA10, PA15 (5 pins)
- **Port B:** PB2, PB3, PB4, PB5, PB8, PB11 (6 pins)
- **Port C:** PC14, PC15 (2 pins)
- **Total Available:** 13 pins

---

## Packet Format - MUST MATCH!

Both use identical packet format:

```
$$lat,lon,alt,sats,fix,launch_status,callsign$$CHKSUM
```

**Example:**
```
$$3953.40363,-10506.93605,1671.7,12,1,45,KE0MZS$$2F
```

### Fields:
1. `lat` - Latitude (NMEA DDMM.MMMMM)
2. `lon` - Longitude (NMEA DDDMM.MMMMM)
3. `alt` - Altitude (meters)
4. `sats` - Satellites in view
5. `fix` - GPS fix quality (0/1/2)
6. `launch_status` - `N` or seconds since launch
7. `callsign` - Ham radio callsign
8. `CHKSUM` - XOR checksum (2 hex digits)

---

## Development Tools

### Transmitter:
- **IDE:** PlatformIO / Arduino IDE
- **Framework:** Arduino (SAMD51)
- **Library:** RadioLib (SX1268 support)
- **Upload:** USB bootloader (double-tap reset)
- **Debug:** Serial monitor via USB

### Receiver:
- **IDE:** Any (VS Code, etc.)
- **Framework:** STM32 HAL
- **Build:** Makefile + arm-none-eabi-gcc
- **Upload:** ST-Link or DFU mode
- **Debug:** SWD (SWDIO/SWCLK pins)

---

## Wiring Complexity

### Transmitter: ⭐⭐ (Simple)
```
3 modules, 13 wires total:
- GPS: 2 wires (RX/TX)
- LoRa: 7 wires (SPI + control)
- IMU: 3 wires (I2C + reset)
- Power: 1 wire (shared 3.3V/GND)
```

### Receiver: ⭐⭐⭐⭐ (Complex)
```
6 modules, 24 wires total:
- GPS: 2 wires (RX/TX)
- LoRa: 7 wires (SPI + control)
- Display: 2 wires (I2C)
- Compass: 2 wires (I2C, shared bus)
- SD Card: 5 wires (SPI + detect)
- Button: 1 wire (+ GND)
- Power: 1 wire (shared 3.3V/GND)
```

---

## Visual Pin Diagrams

### Transmitter (ItsyBitsy M4)
```
         ┌─────────────────┐
    BAT ─┤                 ├─ GND
    GND ─┤                 ├─ USB
    USB ─┤  ItsyBitsy M4   ├─ 13 (LED)
    3.3V─┤                 ├─ 12 (LORA_TXEN)
    ARef─┤                 ├─ 11 (LORA_RST)
     A0 ─┤                 ├─ 10 (IMU_RST)
     A1 ─┤                 ├─ 9  (LORA_DIO1)
     A2 ─┤                 ├─ 7
     A3 ─┤                 ├─ SCL (IMU)
     A4 ─┤                 ├─ SDA (IMU)
     A5 ─┤                 ├─ 6  (LORA_BUSY)
    SCK ─┤   (LoRa SPI)    ├─ 5  (LORA_CS)
   MOSI ─┤   (LoRa SPI)    ├─ 4
   MISO ─┤   (LoRa SPI)    ├─ 3
 TX (1) ─┤  (GPS TX)       ├─ 2
 RX (0) ─┤  (GPS RX)       ├─ RST
         └─────────────────┘
```

### Receiver (STM32F4 Black Pill)
```
         ┌─────────────────┐
   PB12 ─┤ (LORA_CS)       ├─ GND
   PB13 ─┤ (LORA_SCK)      ├─ GND
   PB14 ─┤ (LORA_MISO)     ├─ 3.3V
   PB15 ─┤ (LORA_MOSI)     ├─ RST
    PA8 ─┤ (LORA_RST)      ├─ PB11
    PA9 ─┤                 ├─ PB10 (BUTTON)
   PA10 ─┤                 ├─ PB1  (LORA_DIO1)
   PA15 ─┤                 ├─ PB0  (LORA_BUSY)
    PB3 ─┤  STM32F401      ├─ PA7  (SD_MOSI)
    PB4 ─┤  Black Pill     ├─ PA6  (SD_MISO)
    PB5 ─┤                 ├─ PA5  (SD_SCK)
    PB6 ─┤ (I2C_SCL)       ├─ PA4  (SD_CS)
    PB7 ─┤ (I2C_SDA)       ├─ PA3  (GPS_RX)
    PB8 ─┤                 ├─ PA2  (GPS_TX)
    PB9 ─┤ (SD_DETECT)     ├─ PA1
   5V   ─┤                 ├─ PA0
   GND  ─┤                 ├─ PC15
   3.3V ─┤                 ├─ PC14
         └─────────────────┘
               PC13 (LED)
```

---

## Compatibility Checklist

Before deploying, verify:

### LoRa Settings Match:
- [ ] Frequency: 433.0 MHz
- [ ] Bandwidth: 62.5 kHz
- [ ] Spreading Factor: 10
- [ ] Coding Rate: 4/8
- [ ] Sync Word: 0x12

### Packet Format Matches:
- [ ] Binary typed packets V2: GPS 14 B / fused 20 B / heartbeat 8 B (+ callsign)
- [ ] Same struct layout and scaling in rf_packet.h (TX) vs rf_parser.c (RX)
- [ ] Legacy ASCII path ($$data$$CHKSUM) only if USE_BINARY_PACKETS=0

### Antennas Connected:
- [ ] Transmitter has 433MHz antenna
- [ ] Receiver has 433MHz antenna
- [ ] Both are properly tuned/matched

### Power Supply:
- [ ] Transmitter battery charged (3.7V LiPo)
- [ ] Receiver powered (USB or battery)
- [ ] All modules getting correct voltage (3.3V)

### Testing:
- [ ] Transmitter sends packets (check Serial output)
- [ ] Receiver displays RF data (check RF mode)
- [ ] RSSI/SNR values reasonable (-40 to -120 dBm)
- [ ] GPS lock on both (wait 30-60s)

---

## Troubleshooting: TX → RX Communication

### No Packets Received:

1. **Check LoRa settings match** (most common!)
   - Frequency off by even 0.1 MHz = no reception
   - Wrong spreading factor = incompatible

2. **Check antennas**
   - Transmitter needs antenna to transmit
   - Poor antenna = very short range

3. **Check transmitter is transmitting**
   - USB Serial monitor should show "Transmitted: ..."
   - LED may blink during TX

4. **Check receiver is in RX mode**
   - Display should show RF mode
   - RSSI should update (even if no packets)

5. **Distance too far**
   - Start with TX and RX side-by-side
   - Should see RSSI around -40 to -60 dBm when close

### Garbled/Corrupted Packets:

1. **Interference**
   - Move away from WiFi routers
   - Avoid metal buildings
   - Check for other 433MHz devices

2. **Power supply issues**
   - LoRa needs clean power during TX
   - Add capacitors if voltage sags

3. **Antenna mismatch**
   - Use proper 433MHz antennas
   - Check SWR if using commercial antenna

---

**Both systems ready to deploy!** 🚀

See individual pinout documents for complete details:
- `TRANSMITTER_PINOUTS.md`
- `RECEIVER_WIRING.md`

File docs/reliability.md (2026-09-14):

# Reliability

This document consolidates the defence-in-depth measures the system uses to
avoid transmitting or displaying bad data, and the LoRa link-budget rationale
behind the current radio configuration.

It supersedes the earlier scattered write-ups:

- `RELIABILITY_IMPROVEMENTS.md` (transmitter / GPS validation)
- `RECEIVER_RELIABILITY_IMPROVEMENTS.md` (receiver / signal quality)
- `LORA_RELIABILITY_GUIDE.md` (radio link budget)

---

## 1. Reliability layers at a glance

| Layer | Component | Guards against |
|---|---|---|
| Hardware | LoRa CRC | Bit errors |
| Hardware | LoRa FEC (CR 4/8) | Noise corruption |
| Hardware | GPS multi-constellation | Poor satellite geometry |
| Transmitter | Min 4 satellites | Low-accuracy positions |
| Transmitter | GGA fix-quality >= 1 | No-solution packets |
| Transmitter | Altitude sanity (-500 to 50,000 m) | GPS glitches |
| Transmitter | TX error reporting | Silent radio failures |
| Receiver | RSSI threshold (-120 dBm) | Weak/edge packets |
| Receiver | SNR threshold (-10 dB) | Noise-corrupted packets |
| Receiver | Duplicate filter | Redundant processing |
| Receiver | Staleness timeout (30 s) | Stale position display |
| Receiver | Coordinate validation | "Null Island", 100 km jumps |
| UI | "STALE DATA" / "WEAK SIGNAL" warnings | User confusion |

---

## 2. Transmitter-side validation

Before a packet is transmitted, the beacon runs these checks on the parsed
NMEA data. Failed checks log a reason and skip the transmission.

### 2.1 Minimum satellite count

- Required: **>= 4 satellites** (3-D GPS solution) in flight
- **After the landing latch: >= 3** - a canopy landing often leaves 2-D
  geometry; its horizontal position is exactly what the recovery crew
  walks to. Those packets carry `FLAG_LOW_SATS` (0x20) and report the true
  sat count. Under 3 sats still rejects.
- Example log: `[Beacon] Rejecting GPS - insufficient satellites: 3`

### 2.2 GPS fix-quality indicator (GGA field 6)

| Value | Meaning |
|---|---|
| 0 | Invalid / no fix |
| 1 | Standard GPS fix (SPS) |
| 2 | DGPS fix |
| 3+ | Other (PPS, RTK, ...) |

Required: `quality >= 1`. Example log: `[Beacon] Rejecting GPS - no fix, quality: 0`.

### 2.3 Altitude sanity check

Accepts only altitudes in **-500 m to 50,000 m**. Anything outside is treated
as a GPS glitch and dropped. Example log:
`[Beacon] Rejecting GPS - unreasonable altitude: 123456.7`.

### 2.4 Transmission error reporting

When `RadioLib::transmit()` returns an error, the beacon logs the status code
instead of silently dropping the packet. Example:
`[Beacon] X Transmission failed, error code: -2`.

### 2.5 Launch-detection debouncing

Launch is only declared when the IMU reports acceleration above threshold for
a sustained window (default 100 ms at 20 m/s^2). State machine:
`IDLE -> DETECTED -> CONFIRMED`. Prevents a single sharp bump from triggering
the continuous-transmit state.

---

## 3. Receiver-side validation

### 3.1 Signal quality

Thresholds (in `receiver/firmware/inc/rf_receiver.h`):

```c
#define RF_MIN_RSSI_DBM   -120   /* below SF10/BW62.5/CR4-8 sensitivity ~-134 dBm */
#define RF_MIN_SNR_DB      -10   /* LoRa can decode down to -20 dB */
```

Exposed via:

```c
void    RF_Receiver_GetSignalQuality(int16_t *rssi, int8_t *snr);
uint8_t RF_Receiver_IsSignalQualityGood(void);
```

### 3.2 Staleness detection

```c
#define RF_DATA_STALE_TIMEOUT_MS  30000   /* 30 seconds */
uint8_t  RF_Receiver_IsDataStale(uint32_t current_time_ms);
uint32_t RF_Receiver_GetLastPacketTime(void);
```

Rationale: pre-launch cadence is ~20 s, so a 30 s timeout tolerates one
missed packet. Post-launch cadence is ~2 s, so 30 s equals 15 missed
packets before giving up (tolerant enough for worst-case RF fades during
boost / tipover).

### 3.3 Duplicate filtering

**Currently disabled.** Byte-identical back-to-back duplicates were only
ever produced by the radio re-delivering the same frame, and the LoRa CRC
plus the application checksum already reject corrupted frames, so the
comparison cost was not buying anything. The diagnostics getter still
reports the field but always returns 0.

### 3.4 Coordinate validation

Two different filters live on the receiver and are easy to confuse:

- **Receiver's own GPS** (`gps_parser.c`, our walking position): rejects
  (0,0) "Null Island" and any impossible jump vs. the previous local fix.
- **Rocket telemetry** (`rf_parser.c`): validates lat/lon ranges only.
  Telemetry jumps are handled by other layers instead - the TX-side EKF
  innovation gate rejects bad fixes before they are transmitted, the
  stale-fused override keeps pure dead-reckoning from overwriting a fresh
  raw fix, and the airframe binding (§6b) drops a foreign beacon's
  otherwise-valid coordinates. A large *legitimate* jump (rocket found
  after an over-the-horizon walk) is exactly what must pass, so no
  distance gate is applied to rocket packets.

### 3.5 User-visible warnings

The navigation UI surfaces the state of the data so the operator is never
misled:

```
Distance: 2.5 km
Bearing:  045 deg
[STALE DATA]    <- shown when last packet > 30 s old
[WEAK SIGNAL]   <- shown when RSSI or SNR below threshold
```

Navigation mode continues to point to the **last known good position** when
data is stale, because an out-of-date bearing is still useful for recovery.

---

## 4. LoRa link budget

### 4.1 Current configuration

```c
Frequency:        433 MHz       /* US 70 cm amateur band (8-channel plan) */
Bandwidth:        62.5 kHz      /* +3 dB sensitivity; LDRO on at SF10 */
Spreading factor: SF10          /* chosen for range; fused cadence 1.2 s */
Coding rate:      4/8           /* field evidence favored FEC margin */
TX power:         22 dBm chip   /* drives the M33S module PA (rated 33 dBm) */
Preamble:         16 symbols (TX) / 8 (RX; longer TX preamble is safe)
Sync word:        0x12
```

### 4.2 Budget worked through

- TX power: **+22 dBm**
- TX antenna gain (17 cm whip, ~lambda/4): **+2 dBi**
- Cable loss: **-0.5 dB**
- EIRP: **+23.5 dBm**

- Free-space path loss at 10 km, 433 MHz: **-132 dB**

- RX antenna gain: **+2 dBi**
- RX cable loss: **-0.5 dB**
- RX sensitivity (SF10, BW62.5, boosted gain): **~-134 dBm** (datasheet; the
  local ambient floor measured in field logs (~-70..-75 dBm) is the real cap)

```
Received power = EIRP + RX antenna + RX cable - path loss
               = 23.5 + 2 - 0.5 - 132 = -107 dBm
Link margin    = -107 - (-134) = ~27 dB at 10 km (datasheet floor)
```

**~27 dB of headroom** at 10 km on paper covers typical fading (10-20 dB);
in practice the measured receiver noise environment eats roughly 40 dB of
it - see 4.4 and the 2026-09 range investigation.

**~16 dB of headroom** at 10 km covers typical fading (10-20 dB) at the
edge of practical range; closer in, the margin grows ~6 dB per halving of
distance (e.g. ~34 dB at 2.5 km).

A real flight (Apr 2026, ItsyBitsy + E22 + 17 cm whip, SF7) measured a
worst-case RSSI of -86 dBm at 2.1 km slant range, giving a **37 dB link
margin** at SF7 -- consistent with the budget above.

### 4.3 Configuration trade-offs

| Setting | Range | Air time | Data rate | Use case |
|---|---|---|---|---|
| SF7, 125 kHz | ~4-6 km | 60 ms | 5.5 kbps | Fast updates (10 Hz fused era) |
| SF9, 125 kHz | ~8-12 km | 370 ms | 1.8 kbps | Balanced rocket tracking |
| SF10, 125 kHz | ~12-18 km | 660 ms | 980 bps | Range-first tracking |
| SF10, 62.5 kHz, CR4/8 (default, 2026-09) | ~16-25 km | 0.99 s | 490 bps | + narrowband channel |
| SF11, 62.5 kHz | +3 dB over SF10 | 2.2 s | ~250 bps | Rejected: halves update rate + scan agility for +3 dB |
| SF12, 125 kHz | ~15-25 km | 2.6 s | 290 bps | Not useful for flight |

**Preamble**: default 8 symbols is a good compromise. Increasing to 12-16
improves low-SNR detection with only ~3-5% extra air time.

### 4.4 Antenna is the biggest single lever

Everything above assumes a properly tuned 433 MHz antenna. A mismatched or
broken antenna can cost **10-20 dB** (50-90% range reduction). Checklist:

- IPEX connector fully seated on E22 module
- Antenna is lambda/4 for 433 MHz (~17 cm)
- Polarization matches between TX and RX (both vertical)
- TX antenna has clear line of sight (mounted externally, no metal near)
- SWR below 2.0 in the target band

---

## 5. Regulatory considerations

### 5.1 US (FCC)

- 433.05-434.79 MHz is a secondary allocation inside the 70 cm amateur band
- No 1 W cap: Part 97 allows up to 1500 W PEP on 70 cm. The practical
  ceiling here is the M33S module (~33 dBm / 2 W claimed) - but actual
  radiated power has never been bench-measured; treat that with suspicion
  until a power meter says otherwise
- Beacon self-identifies with the callsign every 5 minutes, twice as often
  as §97.119's 10-minute requirement - including in battery-save state,
  so "end of transmission" ID is covered by the ongoing stream
- No amateur duty-cycle cap exists; throttle anyway: pad pace is sparse for
  GPS-desense reasons, POST_LAUNCH pacing is for PA thermal reasons
- An amateur radio license (Technician class or higher) is required

### 5.2 EU (ETSI)

- **This configuration cannot be made EU-legal by a power change.**
  EU ISM at 433 MHz (EN 300 220) caps power at 10 mW, channels at 25 kHz,
  and duty cycle at 10% - versus this design's ~33 dBm, 62.5 kHz channels,
  and flight-phase streaming. An EU variant would need LPD433 channeling,
  a slow sparse telemetry profile, and the PA disabled.

### 5.3 Other regions

**Check your local regulations before transmitting.**

---

## 6. Tested vs. conservative

Current configuration has been verified on:

- 2 km AGL flight, Mach 0.99 peak, 125 s duration
- 0 packet losses during flight
- RSSI -86 dBm at apogee (2.1 km slant range)
- 37 dB measured link margin

Extrapolating the same RSSI/range pair via free-space loss gives a predicted
usable range on the order of 100 km line-of-sight, but real-world range will
be limited by horizon geometry, terrain, and antenna pattern long before
sensitivity becomes the limit. See `docs/flight-analysis.md` for how
`analyze_flight.py` computes predicted range from flight data.

---

## 6b. Resiliency additions (2026-08-30 review)

Later hardening on top of the layers above. Each has host-side regression
tests (`transmitter/tests`, `receiver/tests`).

### Transmitter

- **EKF innovation gate** (`nav.cpp`): a GPS fix whose normalized innovation
  exceeds chi2(3 dof, 99.9%) AND is > 20 m from the filter estimate is
  rejected as multipath/stale-position. Fails open when the IMU is dead
  (coast-phase innovations are legitimately large).
- **Two-fix anchor confirmation**: the tangent-plane anchor requires two
  consecutive fixes within 30 m of each other inside 10 s. A lone power-on
  glitch fix can no longer anchor the EKF at a wrong origin.
- **GPS watchdog correctness**: recovery keys on a live good fix
  (fix_quality >= 1, sats > 0, bytes flowing) instead of the latched
  `valid` flag, which a stale hot-start position could hold forever.
- **Radio wedge recovery**: TX radio re-inits on sustained TX-complete
  failure; a latched TX failure no longer silences the beacon permanently.
- **IMU-dead reporting**: fused packets carry
  `FUSED_FLAG_SENSOR_DEGRADED` (bit 2) when the BNO085 failed init or went
  silent for > `NAV_SENSOR_DEAD_MS` (2 s) - a level, not a latch, so it
  clears if the wasReset() re-enable brings the chip back. Distinct from
  `FUSED_FLAG_IMU_HEALTHY` (500 ms staleness window).
- **EKF rescue after GPS holes**: 15 s without an accepted fix flips the
  innovation gate (the filter's own coast state is then the suspect, not
  the fixes); rescue acceptance requires a motion-consistent fix pair and,
  past 2 km from the anchor, re-bases the tangent origin with a hard state
  reset. Prevents the 2026-09-11 failure where 5 minutes of windshield
  shadow left phantom velocity the gate then defended forever.
- **Landing-window multipath tolerance**: rockets land in trees and
  gullies where resting GPS throws isolated 20-30 m altitude spikes. A
  single out-of-window sample no longer flushes the 60 s landing-stability
  window (the battery-save transition still happens on time); two
  consecutive out-of-window samples mean the rocket is genuinely still
  sliding and the window restarts.

### Receiver

- **Radio wedge recovery**: a sustained (3 s) not-RX chip mode triggers RX
  re-entry, escalating to a full chip re-init after 3 retries; recoveries
  are SD-logged (`RF wedge recovered`).
- **Auto re-scan**: after contact, > 5 minutes (5x the battery-save
  cadence) without an own/bindable packet re-starts the channel scan
  instead of sitting deaf on a dead channel; foreign chatter on the channel
  does not count as contact.
- **Airframe binding**: position/fused packets and heartbeats carry
  `rocket_id`; the receiver binds to the first airframe ID heard on the
  tuned channel and drops foreign IDs before the parser sees them, so a
  co-channel beacon running this same firmware cannot hijack the nav
  display. Callsigns (`"<CALL>-<id> CH<n>"`) bind and filter by the same
  rule. Legacy V1 packets (no ID byte) always pass - protection is mutual:
  reflash every beacon.
- **Sequential-rocket livelock breaker**: after 3 consecutive auto
  re-scans all ended by foreign traffic (yesterday's rocket is gone, a new
  one is up on this channel), the binding is released once and the next ID
  heard claims the channel.
- **Scan dwell re-arm**: the dwell timer now starts when the chip actually
  enters RX on a channel, not when the hop is commanded - worst-case lock
  time dropped from ~61 s to ~14 s (verified in field logs).
- **Callsign packets delivered in binary mode**: ID packets no longer
  silently dropped.
- **Compass convention-lock guard**: the quaternion heading convention
  search refuses to lock when the device X axis is within 15 deg of a
  45-degree multiple, where two mirror candidates both fit the 12 deg
  acceptance gate; a wrong lock would have mirrored every heading.
- **Headless/display-failure boot**: OLED failure no longer hangs boot;
  the unit runs with radio + SD + watchdog only.
- **Error channel hygiene**: informational messages moved off
  `Compass_SetError(0, ...)` so real faults stay latched and visible.
- **Stale-fused position override**: a fused packet with GPS_FRESH clear
  (pure dead-reckoning) cannot overwrite the displayed position while a
  raw GPS fix arrived within the last 10 s - DR is a hint, the raw stream
  is the measurement. Velocities freeze too in that state.
- **TX-IMU surfacing**: `FUSED_FLAG_SENSOR_DEGRADED` decodes into the nav
  page chip (`SNS!`), the preflight page (`TX IMU CHK dead!`, advisory
  only - a dead IMU still flies on raw GPS + altitude-climb fallback), and
  the SD log (`FusedFlags` bit 0x40). Bit mapping is pinned by mirrored
  wire-format tests in `transmitter/tests/test_beacon.cpp` and
  `receiver/tests/test_rf_parser.c`.

### Tooling

- `tools/log_summary.py` summarizes a session's SD logs into exactly these
  health indicators (wedges, LOST windows, IWDG resets, heartbeat GPS
  states, telemetry gaps, errors) so a flight can be audited in seconds.

## 7. Not-implemented / rejected approaches

These were considered and intentionally **not** added:

- **Packet acknowledgments** -- would require two-way comms, breaks the
  simplex design, would also halve effective TX rate
- **Frequency hopping** -- adds sync complexity for minimal benefit at our
  link margins
- **Adaptive data rate** -- requires an RSSI feedback channel the beacon
  doesn't have
- **Aggressive software filtering at the receiver** -- risks discarding
  valid edge-of-range packets that are actually still useful

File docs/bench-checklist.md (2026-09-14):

# Receiver Bench Checklist

A short power-up checklist for the receiver, focused on things that can only
be verified on hardware. Run it after flashing new firmware and before every
launch weekend. Total time: ~5 minutes with the beacon on the bench.

Firmware verified by this checklist: display geometry fixes, compass error
reporting, SD self-test, LED packet pulse, LoRa link.

## 0. Transmitter USB banner (after every flash)

Connect the beacon over USB and watch the first seconds of boot:

- [ ] `[Radio] Fused time-on-air: NNNN ms, cadence 1500 ms` — the on-air
      time must clear the cadence with a real gap; a `WARNING` line here
      means a packet-format or radio-config change ate the PA duty margin.
- [ ] The callsign line shows the intended `KE0MZS-<id> CH<n>` for this
      airframe.
- [ ] If you INTENDED a testing flash: confirm the receiver's PRE-FLIGHT
      page shows the starred callsign (`TST *KE0MZS-n CHn*`) within ~60 s -
      that path verifies both the beacon and the bench-build detector.
      If you intended production: starred callsign = you flashed a
      TESTING_MODE build; reflash before the pad.

## 1. Boot sequence (just watch the screen)

- [ ] **Test pattern**: `TL` top-left, `TR` top-right, `BL` bottom-left,
      `BR` bottom-right, `CENTER` centered. All four corners must be visible
      and in the right corners — anything shifted or missing means the
      display rotation/geometry regressed.
- [ ] **RF Init**: shows `RF Init / OK / LoRa 433MHz`. An error screen here
      shows `RF Init Err: 0xNN` — note the code.
- [ ] **SD Card**: `SD Card / Ready` then `SD Self-Test / PASS`.
      On FAIL the screen shows `S:<step> FR:<result>` plus
      `CMD:xx DT:xx T:n` — photograph it; see
      `sd-card-troubleshooting.md` for decoding.
- [ ] **Last Beacon**: if a previous flight saved a position, its lat/lon
      shows for 1.5 s and the nav screen has a bearing immediately.
- [ ] **BNO055 Initialized**, with `Cal: Restored` if a calibration was
      saved on the SD card previously.

## 2. LED (PC13)

- [ ] LED is **off** when no packets are arriving (it used to be solid on —
      solid on now means something is wrong).
- [ ] With the beacon transmitting, LED gives a **short blink on every
      packet** (~100 ms). Blink cadence should match the beacon's send rate.

## 3. RF link (beacon on, a few metres away)

- [ ] RF display mode (button-cycle to it): `P: n/n` parse counters climbing,
      `Lat/Lon/Alt` matching the beacon's position, `Fix: Y`.
- [ ] Rows 6–7 show the raw packet ASCII (two 15-char lines).
- [ ] Navigation mode: distance is plausibly small, arrow tracks as you
      rotate the receiver.

## 4. Compass / IMU

- [ ] IMU test mode: real values updating; **deliberately induce an error**
      once (e.g. hold BOOT and disconnect the BNO055 I2C wire briefly) and
      confirm the error line shows an actual message, not `No error` —
      this verifies the error-reporting path end-to-end.

      NOTE: only do the wire-pull test on the bench, never before a flight.
- [ ] Compass heading mode: `Cal S_ G_ A_ M_` — wave figure-8 until `M3`,
      then power-cycle and confirm `Cal: Restored` on boot.

      IMPORTANT: after a restore the BNO055 still reports `S0 G0 A0 M0` until
      fresh motion re-verifies — that is normal, NOT a lost calibration. The
      cal row shows a trailing `R` when verified offsets are loaded, and the
      heading is already trustworthy. `Cal: RESTORE FAILED` on the boot screen
      means the read-back verification failed and the compass really is
      uncalibrated. The saved calibration lives on the SD card - booting
      without the card always starts uncalibrated.
- [ ] Heading sanity: point the antenna north, heading reads ~0°
      (declination is compiled for the Denver area — see
      `COMPASS_MAGNETIC_DECLINATION_DEG` in `compass.c` before travelling).

## 5. SD logging round-trip (weekend-before check)

- [ ] Receive ≥10 packets from the beacon, power off, pull the card.
- [ ] `make extract DEV=/dev/sdX OUT=/tmp/bench` — expect `BEACON.TXT`,
      `COMPCAL.BIN`, and a new `Lnnnn.TXT`.
- [ ] `python3 receiver/tools/analyze_flight.py /tmp/bench/Lnnnn.TXT` —
      must print packet counts (a bench log will say "No launch detected",
      which is correct). If it says "Not enough NAV rows", the firmware
      log format and the tools have drifted — run `make tools-test`.

## Field notes

- Button cycles: Navigation → GPS → RF → Compass Visual → Compass Heading →
  SD Card → Rocket Select (long-press cycles channel) → RF Stats →
  Preflight → back. Any screen auto-returns to Navigation after 120 s.
- Remote position goes stale (nav arrow frozen, `has_valid_remote_gps`
  dropped) after **180 s** without a packet.
- BEACON.TXT persists at most every **10 s**, so a power cut can lose up to
  10 s of last-known-position; the per-packet NAV log is synced every row
  and loses nothing.

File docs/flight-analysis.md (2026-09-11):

# Flight analysis

`receiver/tools/analyze_flight.py` turns a receiver SD-card log into:

1. A printed summary of altitude, velocity, horizontal drift, and RF link stats
2. A free-space-path-loss prediction of the maximum usable range
3. (Optional) A Google-Earth KML with a time-animated flight replay
4. (Optional) A headless MP4 3-D flight replay rendered via matplotlib + ffmpeg

The log is the plain-text CSV the receiver firmware writes to the SD card.
Only `NAV` rows (with GPS + RSSI) are analysed; other row types are ignored.

## Requirements

- Python 3.8+ (standard library only for analysis + KML)
- `matplotlib` and a working `ffmpeg` on `PATH` **only if** you want MP4 output

```bash
pip install matplotlib
sudo apt install ffmpeg        # or the equivalent on your OS
```

## Usage

```bash
python3 receiver/tools/analyze_flight.py /path/to/Lxxxxxxx.TXT [OPTIONS]
```

### Options

| Flag | Default | Purpose |
|---|---|---|
| `--sensitivity DBM` | `-134` | Receiver sensitivity floor for range prediction (LoRa SF10 / 62.5 kHz). Use `-131` for the SF10 / 125 kHz era, `-123` for SF7-era logs. |
| `--kml PATH` | off | Write a Google-Earth KML of the flight (trajectory + animated rocket + pad/apogee/landing placemarks). |
| `--mp4 PATH` | off | Render a 3-D animated MP4 directly. Requires `matplotlib` + `ffmpeg`. |
| `--fps N` | 30 | MP4 frame rate. |
| `--speedup N` | 1.0 | MP4 playback speed (1.0 = real-time, 4.0 = 4x faster). |
| `--duration N` | auto | MP4 total duration in seconds; overrides `--speedup`. |
| `--pre-launch N` | 2.0 | Seconds of pad lead-in shown in the MP4 before T+0. |

## Output sections

The printed summary has six sections:

```
FLIGHT ANALYSIS  (Lxxxxxxx.TXT)
--- ALTITUDE                        apogee MSL/AGL, final altitude
--- VELOCITY / ACCEL                peak ascent/descent rate, peak |a| in G
--- HORIZONTAL / RECOVERY           max drift, ground track, landing offset
--- RF LINK                         pre/post-launch cadence, RSSI range
--- PREDICTED RANGE                 FSPL extrapolation from worst RSSI
--- LINK CONTINUITY                 in-flight packet gaps
```

### Altitude

Ground level is taken from the **first pre-launch sample**. Launch is
declared when altitude rises >10 m above ground. AGL values are relative
to that reference.

### Velocity / acceleration

Derivatives are computed by central difference over the packet cadence
(~1.7 s during flight with the continuous-send firmware). These peaks are
**always underestimates** of the true instantaneous values -- a real Mach
1 rocket reaches ~340 m/s in under a second, so with 1.7 s sampling the
averaged peak can be much lower than reality.

### Horizontal / recovery

Uses a flat-Earth ENU projection centered on the pad -- good to ~0.1 m for
the few-km scales typical of an amateur flight. Ground track is the
integrated path length, not straight-line displacement.

### RF link

Pre-launch cadence is 5 s across packet types while range-testing (dense);
the flight-prep regime paces them at 30 s so the pad's full-power bursts
leave GPS front ends alone. Post-launch is paced (raw every 2 s, fused
every 1.2 s). The "TX rate boost" column shows the in-flight rate delta.

### Predicted range

Takes the **worst in-flight RSSI** paired with the **slant range at that
moment** (i.e., includes altitude as well as horizontal distance). Applies
free-space path loss (20 * log10(d)) to extrapolate to the sensitivity
floor.

Caveats:

- Assumes free space -- real horizon, terrain, and antenna patterns will
  limit range well before this number.
- Uses a single RSSI/range pair; noisier fits may give larger predictions
  than the real link can deliver.
- Override `--sensitivity` to match your actual LoRa configuration.

### Link continuity

Reports in-flight packet gaps exceeding the expected cadence + 1.5 s. A
flight with zero gaps means signal was never lost -- the log ending does
not imply signal loss (usually the receiver was powered off after recovery).

## Pad-reference robustness

Two subtle-but-important fixes live in the MP4 renderer:

- The **vertical reference** uses the first pre-launch sample's altitude,
  not `rows[launch_idx]["alt"]`. The launch-detect sample can already be
  hundreds of metres up because of the 1.7 s cadence, and using it would
  place the descent below the ground plane.
- The **horizontal reference** uses the median of pre-launch samples
  captured within the last 60 s before launch. This handles the common
  case where the beacon/RX is powered on in the prep tent and walked to
  the pad -- using all pre-launch samples would drift the pad marker.

If your log shows the rocket still airborne at the last packet (log ended
mid-flight), the "Landing offset" in the summary is really the
last-known-position offset, not the actual landing point.

## Google-Earth replay (`--kml`)

Produces a KML with:

- A static red LineString of the full trajectory (altitude-accurate)
- A `<gx:Track>` with per-packet timestamps that Google Earth's time
  slider replays in 3-D
- Styled placemarks for launch pad (green), apogee (yellow star), and the
  last packet (red)

Open the file in **Google Earth Pro** (free). To export video:
`Tools > Movie Maker`.

The web version of Google Earth renders the trajectory but does not have
Movie Maker.

## Headless MP4 (`--mp4`)

Fully scripted; no GUI needed. Produces:

- 3-D plot in local ENU metres around the pad
- Cyan trailing line showing the traversed path
- Yellow moving rocket marker with ground-shadow trail
- Static placemarks (launch pad, apogee, last packet)
- Live HUD: T+, altitude AGL, east/north offset, RSSI
- Slowly orbiting camera
- Progress indicator during render

Matplotlib 3-D rendering is slow (~0.3-0.5 s per frame at 100 dpi). A
real-time render of a 2-minute flight takes ~15 minutes. For quick
previews use `--speedup 8` or `--duration 15`.

## Example

```bash
$ python3 receiver/tools/analyze_flight.py /media/you/SD/L000314A.TXT \
      --kml flight.kml --mp4 flight.mp4 --duration 20

FLIGHT ANALYSIS  (L000314A.TXT)
Launch pad:      38.156120, -104.808723
Ground (MSL):    1667 m (5469 ft)
Flight duration: 125.1 s
Time to apogee:  16.1 s

--- ALTITUDE ---
  Apogee AGL:   2041 m  (6697 ft)

--- VELOCITY / ACCEL ---
  Max ascent rate:  339.1 m/s (Mach 0.99)

--- RF LINK ---
  Worst RSSI: -86 dBm at T+20s

--- PREDICTED RANGE ---
  Link margin at anchor: 37.0 dB
  Predicted max range:   150 km  (FSPL, LOS)
  Reached this flight:   2.1 km  (1.4% of predicted max)

--- LINK CONTINUITY ---
  No in-flight packet gaps > expected cadence + 1.5s

KML written: flight.kml
Rendering MP4 to flight.mp4 ...
  Frames: 600  (20.0s @ 30fps)  ~estimated render: 4.0 min
  rendering:  600/600  (100.0%)  elapsed 245.1s  ETA   0.0s
MP4 written: flight.mp4
```

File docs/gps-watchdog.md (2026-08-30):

# GPS Watchdog - Automatic Recovery System

## Summary
Automatic detection and recovery system for GPS module hangs, eliminating the need for manual power cycles.

## The Problem

GPS modules can occasionally enter unrecoverable states:

### Symptom 1: UART Dead
```
[GPS] Bytes rcvd: 0 | Valid: 0
[GPS] Bytes rcvd: 0 | Valid: 0  <-- No data at all
[GPS] Bytes rcvd: 0 | Valid: 0
```
**Cause:** GPS module stopped transmitting on UART

### Symptom 2: GPS Stuck
```
[GPS] Bytes rcvd: 5243 | Valid: 0
[GPS] Bytes rcvd: 6891 | Valid: 0  <-- Receiving data but no valid fix
[GPS] Bytes rcvd: 8432 | Valid: 0
```
**Cause:** GPS can't acquire satellites or stuck in invalid state

### Previous Solution
❌ **Power cycle required** - not ideal for flight systems!

## ✅ New Solution: GPS Watchdog

Automatically detects problems and attempts recovery **without power cycle**.

## How It Works

### Detection System

The watchdog monitors two conditions:

#### 1. **No UART Data (Dead GPS)**
- **Trigger:** No bytes received for **30 seconds**
- **Indicates:** GPS UART communication failure
- **Action:** Send GPS reset commands and reinitialize

#### 2. **No Valid Fix (Stuck GPS)**
- **Trigger:** Receiving data but no valid fix for **60 seconds**
- **Indicates:** GPS can't acquire satellites or internal state corruption
- **Action:** Send cold restart command and reinitialize

### Recovery Actions

When a problem is detected:

```
[GPS] ⚠️  Watchdog: No UART data for 30s, attempting recovery...
```

**Step 1: Send Reset Commands**
- u-blox PUBX poll request
- u-blox controlled software reset (cold start) - deliberately NEVER the
  factory-defaults variant: that reverts UART1 to 9600 baud and we talk
  at 115200, permanently deafening the link the recovery meant to restore
- Wait for GPS to restart

**Step 2: Reinitialize GPS**
- Reconfigure NMEA messages
- Reset UART buffers
- Restart sentence parsing

**Step 3: Monitor Result**
```
[GPS] Recovery attempt complete
[GPS] Bytes rcvd: 125 | Valid: 1  ✅ Success!
```

### Safety Features

#### Attempt Limiting with Cooldown
- **3 recovery attempts**, then a **10-minute cooldown**, then re-arm for
  another round - "power cycle required" is not an option on a rocket in
  a tree, but a continuous cold-restart loop would keep discarding the
  almanac
- The cooldown/re-arm cycle runs indefinitely until a fix returns
- The heartbeat's `rst` nibble reports the attempt count (0-15) so the
  receiver display shows recovery activity (0 = GPS healthy)

```
[GPS] ✗ Recovery failed after 3 attempts - cooling down before retry
[GPS] Watchdog: cooldown over, re-arming recovery
```

#### Success Reset
- When GPS gets valid fix, recovery counter resets
- Allows future recovery attempts if needed

## Example Scenarios

### Scenario 1: Successful Recovery (UART Dead)

```
T+0s:  [GPS] Bytes rcvd: 5000 | Valid: 1     (Working normally)
T+30s: [GPS] Bytes rcvd: 5000 | Valid: 0     (GPS stopped)
T+60s: [GPS] Bytes rcvd: 5000 | Valid: 0     (Still stuck)
T+90s: [GPS] ⚠️  Watchdog: No UART data for 30s, attempting recovery...
T+92s: [GPS] Recovery attempt complete
T+95s: [GPS] Bytes rcvd: 5125 | Valid: 0     (Data flowing again)
T+120s: [GPS] Bytes rcvd: 5623 | Valid: 1    ✅ Fixed!
```

### Scenario 2: Successful Recovery (No Fix)

```
T+0s:  [GPS] Bytes rcvd: 1000 | Valid: 1     (Working normally)
T+30s: [GPS] Bytes rcvd: 2500 | Valid: 0     (Lost fix - maybe indoors)
T+90s: [GPS] Bytes rcvd: 4200 | Valid: 0     (Still no fix, still receiving)
T+120s: [GPS] ⚠️  Watchdog: No valid fix for 60s, attempting recovery...
T+122s: [GPS] Recovery attempt complete
T+150s: [GPS] Bytes rcvd: 5800 | Valid: 1    ✅ Fixed!
```

### Scenario 3: Persistent Failure (Cooldown)

```
T+0s:    [GPS] Bytes rcvd: 0 | Valid: 0      (GPS dead)
T+30s:   [GPS] ⚠️  Watchdog: No UART data for 30s, attempting recovery... (Attempt 1)
T+60s:   [GPS] ⚠️  Watchdog: No UART data for 30s, attempting recovery... (Attempt 2)
T+90s:   [GPS] ⚠️  Watchdog: No UART data for 30s, attempting recovery... (Attempt 3)
T+120s:  [GPS] ✗ Recovery failed after 3 attempts - cooling down before retry
T+10min: [GPS] Watchdog: cooldown over, re-arming recovery
T+10.5m: [GPS] ⚠️  Watchdog: No UART data for 30s, attempting recovery... (Attempt 1, round 2)
```

## U-blox Commands Used

### PUBX,00 - Poll Request
```
$PUBX,00*33\r\n
```
- Forces GPS to output current position
- Verifies UART communication

### PUBX,04 - Reset Command
```
$PUBX,04,0,0,0,0,0*10\r\n    // Factory reset (warm start)
$PUBX,04,0,0,2,0,0*12\r\n    // Cold start (clear ephemeris)
```

**Reset Types:**
- **Warm start:** Keeps satellite ephemeris, faster acquisition
- **Cold start:** Clears everything, forces full satellite search

## Configuration

### Watchdog Thresholds

```cpp
// In gps.cpp - gps_poll_rx() function

// UART dead detection
if (no_bytes_duration > 30000)  // 30 seconds

// No fix detection  
if (no_valid_duration > 60000)  // 60 seconds
```

**Tuning:**
- **Shorter timeouts:** Faster recovery, more false positives
- **Longer timeouts:** Fewer false positives, slower recovery
- **Current values:** Good balance for most scenarios

### Maximum Recovery Attempts

```cpp
if (gps_recovery_attempts < 3)  // Max 3 attempts
```

**Why 3?**
- Gives multiple chances for transient issues
- Prevents infinite loops
- If 3 fails, hardware issue likely

## False Positive Prevention

The watchdog is designed to avoid false triggers:
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

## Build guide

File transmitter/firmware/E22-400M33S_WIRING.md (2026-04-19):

# E22-400M33S LoRa Module Wiring Guide

## Module Overview

**E22-400M33S** - Ebyte LoRa module
- Chip: Semtech SX1268
- Frequency: 410-493 MHz (configured for 433 MHz)
- Power: Up to 30 dBm (1W) - configured for 22 dBm
- Interface: SPI
- Range: Up to 15km line-of-sight with good antennas

## Pin Connections

### ItsyBitsy M4 Express → E22-400M33S

| ItsyBitsy M4 | E22-400M33S | Function |
|---|---|---|
| **5** | NSS | SPI Chip Select |
| **9** | DIO1 | Interrupt (TX/RX Done) |
| **6** | BUSY | Module Busy Status |
| **11** | NRST | Reset |
| **12** | TXEN | TX Enable (optional) |
| **MOSI** | MOSI | SPI Data Out |
| **MISO** | MISO | SPI Data In |
| **SCK** | SCK | SPI Clock |
| **3.3V** | VCC | Power (3.3V) |
| **GND** | GND | Ground |

### Hardware SPI Pins on ItsyBitsy M4
- **MOSI**: Pin labeled MOSI on board
- **MISO**: Pin labeled MISO on board  
- **SCK**: Pin labeled SCK on board

## Wiring Notes

1. **Power**: E22-400M33S needs **3.3V**. ItsyBitsy M4 has a 3.3V output pin.
2. **Antenna**: **CRITICAL** - Always connect a 433MHz antenna before powering on! Operating without an antenna can damage the RF amplifier.
3. **TX Enable**: Pin 12 (TXEN) is optional. Some E22 modules don't use this pin.
4. **Logic Levels**: All signals are 3.3V compatible (perfect for ItsyBitsy M4).

## LoRa Configuration

Current settings in `include/mpu_config.h`:

```cpp
#define LORA_FREQUENCY      433.0       // 433 MHz
#define LORA_BANDWIDTH      125.0       // 125 kHz bandwidth
#define LORA_SPREADING      9           // Spreading Factor 9
#define LORA_CODING_RATE    7           // Coding Rate 4/7
#define LORA_SYNC_WORD      0x12        // Private network
#define LORA_TX_POWER       22          // 22 dBm (~160mW)
#define LORA_PREAMBLE       8           // 8 symbols
```

### Range vs Speed Trade-offs

**Current Settings (SF9, BW125):**
- Range: ~5-8 km line-of-sight
- Speed: ~2 kbps
- Air time: ~1 second per packet
- Good balance for rocketry

**For Maximum Range (SF12, BW125):**
```cpp
#define LORA_SPREADING      12          // Slower but longer range
```
- Range: ~10-15 km line-of-sight
- Speed: ~250 bps
- Air time: ~4 seconds per packet

**For Faster Updates (SF7, BW250):**
```cpp
#define LORA_SPREADING      7
#define LORA_BANDWIDTH      250.0
```
- Range: ~2-3 km
- Speed: ~11 kbps
- Air time: ~200ms per packet

## Antenna Requirements

### For 433 MHz:
- **Quarter-wave**: 17.3 cm straight wire
- **Half-wave dipole**: 34.6 cm total (17.3 cm each side)
- **Commercial**: Any 433 MHz LoRa antenna (spring or whip)

**WARNING**: Never transmit without an antenna connected!

## Power Consumption

- **Standby**: ~2 mA
- **Receiving**: ~15 mA
- **Transmitting (22 dBm)**: ~120 mA

The firmware puts the radio in standby between transmissions to save power.

## Packet Format

Same as before - fully compatible with existing receiver:

```
$$lat,lon,alt,sats$$CHECKSUM
```

Example:
```
$$3953.40363,-10506.93605,1671.7,12$$2F
```

The LoRa layer adds:
- Forward Error Correction (FEC)
- CRC checking
- Preamble detection
- Much better sensitivity than simple FSK

## Testing

### Monitor Serial Output

```bash
make flash
make monitor
```

You should see:
```
[Radio] Initializing E22-400M33S (SX1268)...
[Radio] ✓ Initialized successfully
[Beacon] Transmitting callsign: KE0MZS
[Beacon] Transmitting GPS packet: $$...$$XX
[Radio] ✓ Transmitted XX bytes
```

### Verify with LoRa Receiver

On the receiver side, you'll need to update to use LoRa as well. The receiver should:
1. Use same frequency (433.0 MHz)
2. Use same spreading factor (9)
3. Use same bandwidth (125 kHz)
4. Use same sync word (0x12)

## Troubleshooting

### "Initialization failed, code: -2"
- Check SPI connections (MOSI, MISO, SCK)
- Verify NSS (CS) pin connection
- Check 3.3V power supply

### "Transmission failed, code: -7"
- Module is BUSY - normal during transmission
- Wait for transmission to complete

### No signal on receiver
- Verify antenna is connected
- Check frequency matches on both sides
- Confirm spreading factor and bandwidth match
- Try increasing TX power to 30 dBm (max):
  ```cpp
  #define LORA_TX_POWER       30
  ```

### Range is poor
- Check antenna connection and quality
- Increase spreading factor (9 → 10 → 11 → 12)
- Ensure good line-of-sight
- Check for RF interference

## Receiver Updates Needed

Your receiver (STM32F401) will also need to be updated to use LoRa. Key changes:

1. Replace simple RF receiver with E22-400M33S or compatible
2. Install RadioLib on receiver
3. Configure for receive mode with matching parameters
4. Parse LoRa packets (same `$$...$$` format inside)

The existing packet parser will work - just the physical layer changes from FSK to LoRa.

## Advantages Over Simple 433MHz

✅ **10-15x better range** - typical 5-8km vs ~500m  
✅ **Error correction** - FEC recovers corrupted bits  
✅ **Better sensitivity** - Can receive weaker signals  
✅ **CRC built-in** - Automatic packet validation  
✅ **Frequency hopping** - Can implement for reliability  
✅ **Commercial modules** - Cheap, widely available  

## Legal/Regulatory

**433 MHz ISM Band** (varies by country):
- **US**: 433.05-434.79 MHz, max 1W
- **EU**: 433.05-434.79 MHz, max 10 mW (10 dBm)
- **Check local regulations** before use

Current config uses 22 dBm (~160mW) which is legal in US but may need reduction in EU:
```cpp
#define LORA_TX_POWER       10  // For EU compliance
```

## References

- [RadioLib Documentation](https://jgromes.github.io/RadioLib/)
- [SX1268 Datasheet](https://www.semtech.com/products/wireless-rf/lora-core/sx1268)
- [E22-400M33S Manual](https://www.ebyte.com/en/product-view-news.html?id=1123)

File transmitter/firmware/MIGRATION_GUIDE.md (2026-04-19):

# Migration Guide: ATtiny412 → ItsyBitsy M4 Express

## Summary of Changes

### Hardware Platform
- **From**: ATtiny412 (8-bit AVR @ 20MHz, 256B RAM, 4KB Flash)
- **To**: ItsyBitsy M4 Express (32-bit ARM Cortex-M4 @ 120MHz, 192KB RAM, 512KB Flash)

### Build System
- **From**: AVR-GCC with custom Makefile
- **To**: Arduino framework with arduino-cli

### Pin Mapping

| Function | ATtiny412 | ItsyBitsy M4 |
|---|---|---|
| Radio TX | PA2 | Pin 11 |
| Radio Enable | PA0 | Pin 12 |
| Launch Detect | PA1 | Pin 10 |
| GPS RX | PA7 (bit-banged) | Pin 0 (HW Serial1) |
| GPS TX | PA6 (bit-banged) | Pin 1 (HW Serial1) |

### Code Changes

#### 1. Timer System
**Before (ATtiny412)**:
```c
ISR(TCB0_INT_vect) {
    ms_counter++;
    // Timer interrupt at hardware level
}
```

**After (ItsyBitsy M4)**:
```cpp
void loop() {
    static uint32_t last_millis = 0;
    uint32_t current_millis = millis();
    if (current_millis != last_millis) {
        timer_isr_handler();
        last_millis = current_millis;
    }
}
```

#### 2. GPIO Operations
**Before**:
```c
PORTA.OUTSET = (1 << PIN_RADIO_OUT);
PORTA.OUTCLR = (1 << PIN_RADIO_OUT);
```

**After**:
```cpp
digitalWrite(PIN_RADIO_TX, HIGH);
digitalWrite(PIN_RADIO_TX, LOW);
```

#### 3. UART Communication
**Before (bit-banged)**:
```c
USART0.BAUD = USART0_BAUD_RATE(115200);
USART0.CTRLB |= USART_RXEN_bm | USART_TXEN_bm;
```

**After (Hardware Serial)**:
```cpp
GPS_SERIAL.begin(115200);
GPS_SERIAL.available();
GPS_SERIAL.read();
GPS_SERIAL.write(data);
```

#### 4. Delays
**Before**:
```c
#include <util/delay.h>
_delay_ms(100);
_delay_us(10);
```

**After**:
```cpp
delay(100);
delayMicroseconds(10);
```

#### 5. Watchdog
**Before**:
```c
#include <avr/wdt.h>
wdt_reset();
wdt_disable();
_PROTECTED_WRITE(WDT.CTRLA, WDT_PERIOD_8KCLK_gc);
```

**After**:
```cpp
// Not needed - SAMD51 watchdog not enabled by default
// Can be added later if needed
```

#### 6. Interrupts
**Before**:
```c
cli();  // Disable interrupts
sei();  // Enable interrupts
```

**After**:
```cpp
noInterrupts();  // If needed
interrupts();    // If needed
// Generally not needed in Arduino
```

### File Renaming
- `*.c` → `*.cpp` (C++ for Arduino)
- `main.c` → `main.cpp`
- Added `gps_radio_beacon.ino` (Arduino sketch wrapper)

### Configuration Files

#### mpu_config.h (now ItsyBitsy M4 config)
```cpp
#define F_CPU 120000000UL        // 120MHz (was 20MHz)
#define PIN_RADIO_TX 11          // Digital pin (was PA2)
#define PIN_RADIO_ENABLE 12      // Digital pin (was PA0)
#define PIN_LAUNCH_DETECT 10     // Digital pin (was PA1)
#define GPS_SERIAL Serial1       // Hardware serial (was USART0)
#define BEACON_CALLSIGN "KD0ABC" // Your callsign
```

### Removed Dependencies
- `<avr/io.h>` - AVR hardware registers
- `<avr/interrupt.h>` - AVR interrupts
- `<avr/wdt.h>` - AVR watchdog
- `<util/delay.h>` - AVR delay functions
- ATtiny device pack headers

### Added Dependencies
- `<Arduino.h>` - Arduino framework
- No external libraries required

## Performance Improvements

### CPU Speed
- **6x faster**: 120MHz vs 20MHz
- More headroom for future features

### Memory
- **768x more RAM**: No more buffer overflow concerns
- **128x more Flash**: Room for extensive features

### Peripherals
- **Hardware UART**: Reliable GPS communication
- **USB Serial**: Built-in debugging
- **Hardware FPU**: Fast floating-point math (if needed)
- **DMA**: Can offload repetitive tasks (future)

## Advantages

### Development
1. **USB debugging**: `Serial.println()` for diagnostics
2. **No programmer needed**: USB bootloader built-in
3. **Faster uploads**: ~2 seconds vs ~30 seconds
4. **No fuse programming**: Just plug and program

### Reliability
1. **Hardware UART**: No GPS bit-timing issues
2. **More RAM**: No stack overflow risks
3. **Better timing**: 120MHz precision for radio TX

### Flexibility
1. **Add sensors**: I2C, SPI peripherals
2. **SD card logging**: SPI interface available
3. **Real-time clock**: Built-in RTC
4. **More telemetry**: RAM for buffering

## Testing Checklist

- [ ] Install arduino-cli
- [ ] Run `make install-deps`
- [ ] Update callsign in config
- [ ] Connect ItsyBitsy M4 via USB
- [ ] Run `make flash`
- [ ] Connect GPS module to pins 0/1
- [ ] Connect radio module to pins 11/12
- [ ] Connect launch switch to pin 10
- [ ] Test in TESTING_MODE first
- [ ] Verify GPS data reception
- [ ] Verify radio transmission (300 baud)
- [ ] Test launch detection
- [ ] Test state transitions
- [ ] Switch to production mode

## Backward Compatibility

The packet format remains **100% compatible** with the ATtiny412 version:
- Same 300 baud transmission
- Same `$$data$$CHKSUM` format
- Same NMEA coordinate format
- Existing receivers will work without changes

## Future Enhancements

Now possible with ItsyBitsy M4:

1. **Data logging**: SD card via SPI
2. **Better GPS**: UBX binary protocol support
3. **Sensor fusion**: Add IMU for better tracking
4. **Power management**: Sleep modes for battery life
5. **Configuration**: USB serial command interface
6. **Diagnostics**: Detailed telemetry and health monitoring
7. **Dual GPS**: Compare two GPS modules for accuracy
8. **Advanced features**: Geofencing, altitude triggers, etc.

## Troubleshooting

### Compilation fails
```bash
arduino-cli core update-index
arduino-cli core install adafruit:samd
```

### Upload fails
- Press reset button twice quickly to enter bootloader
- Red LED should pulse
- Try different USB cable/port

### GPS not working
- Verify 3.3V power to GPS
- Check TX/RX connections (note: GPS TX → Pin 0, GPS RX → Pin 1)
- GPS baud rate must be 115200
- Use `make monitor` to see debug output

### Radio not transmitting
- Verify 300 baud on pin 11 with oscilloscope/logic analyzer
- Check enable signal on pin 12
- Bit width should be 3333 microseconds (300 baud)

## Support

For issues specific to this port, check:
1. `README_ITSYBITSY_M4.md` - Detailed setup guide
2. Pin assignments in `include/mpu_config.h`
3. Arduino Serial monitor for debug output
4. Adafruit ItsyBitsy M4 documentation

## Credits

Original ATtiny412 firmware: Jamie Bowen
ItsyBitsy M4 port: Cascade AI Assistant
Board: Adafruit ItsyBitsy M4 Express (SAMD51)

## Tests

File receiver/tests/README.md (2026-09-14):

# Receiver Host-Side Unit Tests

Unit tests for hardware-independent receiver firmware modules, compiled and
run on the development machine (no STM32 hardware or ARM toolchain needed).

## Running

```bash
make            # build and run all tests
make coverage   # run with gcov and print line-coverage for modules under test
make clean
```

## What is covered

| Module | Test file | Line coverage (Sept 2026) |
|---|---|---|
| `rf_parser.c` — all 3 RF packet formats from the transmitter | `test_rf_parser.c` | 100% |
| `gps_parser.c` — local NMEA parser (checksum, GGA/RMC, jump filter) | `test_gps_parser.c` | 100% |
| `math_utils.c` — haversine distance, bearing, angle normalization | `test_math_utils.c` | 100% |
| `rf_receiver.c` — scan/wedge/reacquisiton/blackout pacing | `test_rf_receiver.c` | 99.3% |
| `button.c` — debounce/short/long-press policy | `test_button.c` | 100% |
| `display.c` — SSD1309 driver incl. headless I2C fault ladder | `test_display.c` | 100% |
| `gps.c` — sentence RX path, FIFO drop-oldest, watchdog | `test_gps.c` | 97.0% |
| `sd_card.c` — LittleFS logging incl. dirty-card & IO-error throttle | `test_sd_card.c` | 87.1% |
| `lora.c` — SX1268 driver incl. CAD/DC-DC regime | `test_lora.c` | 100% |
| `compass.c` — BNO055 incl. declination lattice & quat-lock | `test_compass.c` | 100% |
| `navigation_mode.c` — L/O/D arrow, state decay | `test_navigation_mode.c` | (not measured: UI-critical only) |

(The transmitter's EKF is tested separately in `transmitter/tests/`, ~100%.)

`rf_parser.c` decodes every packet format sent by the transmitter:

| Format | Parser | Size |
|---|---|---|
| ASCII CSV (`lat,lon,alt[,sats]` / callsign) | `RF_Parser_ParseAsciiPacket` | variable |
| Binary GPS fix | `RF_Parser_ParseBinaryPacket` | 14 B (V2, +rocket_id), 13 B legacy V1 |
| EKF fused position + velocity | `RF_Parser_ParseFusedPacket` | 20 B (V2, +rocket_id), 19 B legacy V1 |

`test_rf_receiver.c` additionally carries the launch-day scenario battery:
airframe binding and foreign-beacon filtering (same-modem co-channel
traffic), the sequential-rocket livelock breaker, over-the-horizon
blackout/re-acquisition, fringe CRC-error forensics, 49.7-day tick
wraparound, and receiver cold-boots mid-flight / mid-walk.

Tests include NMEA→decimal-degree conversion accuracy, hemisphere signs,
malformed/NULL/short packet rejection, coordinate range validation, flag
decoding, and regression guards for two subtle behaviors:

- Fused packets must not overwrite the raw-GPS `fix` field (UI label flapping).
- Raw GPS packets must not zero the fused velocity fields (speed display
  flickering to 0.0 m/s).

`test_gps_parser.c` builds its NMEA fixtures with a checksum-computing
helper, so sentences can never fail due to a hand-computed checksum typo.
Note `gps_parser.c` keeps static jump-filter state with no reset API, so
all valid-fix fixtures use the same geographic area.

## How it works

`stubs/` contains minimal stand-ins for `stm32f4xx_hal.h` /
`stm32f4xx_hal_uart.h` so the real firmware sources compile unmodified with
the host `gcc`. Keep stubs behavior-free; tests must remain
hardware-independent.

## Adding tests

Add a `TEST(name) { ... }` block in the relevant `test_<module>.c` and call
`run_<name>()` from `main`. Use `CHECK(cond)` / `CHECK_NEAR(a, b, tol)` from
`test_harness.h`. To cover a new pure-logic module, create
`test_<module>.c` and append `<module>` to `MODULES` in the Makefile — the
binary is automatically linked against `../firmware/src/<module>.c`.

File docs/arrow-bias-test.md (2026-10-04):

# Arrow-bias measurement procedure

How to reproduce and quantify the "arrow points some degrees off true"
complaint seen in the field (reported ~12:30–1 o'clock at ~1 km).

## Why a procedure and not a bench calibration

The arrow is `compass_heading - bearing_to_last_known`: any bias comes from
one of three layers:

1. **Magnetic declination** at the site. (Now handled automatically by the
   CONUS declination grid, applied at first local GPS fix - this procedure
   measures what remains.)
2. **Fixed mounting offset** of the BNO055 relative to the antenna face.
3. **Soft/hard-iron anomalies** around the case.

Procedure is designed so residual #2 and #3 cancel their own signs over a
quarter-circle sample, leaving a good estimate of #2 alone.

## Procedure (field)

**Critical**: the receiver needs to log rows where you **deliberately point
at the target** — scatter from ordinary walking-around-then-looking-down
rows, which dominate a normal field log, aren't usable. (The existing launch
log already gives false-precision: a whole-file median against the pad sits
at ~76° error even though the arrow was healthy, because most of a walk is
look-at-the-feet time.)

1. Place the beacon (or any GPS-reported target) at a known point. Don't
   move it for the duration.
2. Make the card non-stale: boot the receiver fresh, allow a position fix,
   let scan lock on to the beacon.
3. Open the navigation page — confirm a live target (not the card-restore
   state).
4. Stand ~15-25 m from it; deliberate facing protocol:
   - Face the target, hold the receiver at chest height, square shoulders,
     5 seconds minimum. Walk 10-15° along a circle around the target.
     Repeat at ~8 stations evenly spread.
   - No sideways drift counting: stop, face, then resume.
   - Toss midway: a couple of "trap" walks where you rotate the receiver
     upside-down between facings (to know if roll corruption shows).
5. Stop the recording, pull the card, extract: `make extract DEV=/dev/sdX`.

## Analysis

```
python3 receiver/tools/heading_residuals.py flight_data/<dump>/L000N.TXT
```

Reads the NAV rows and prints a median of `(heading - bearing)` over the
walk. That number is the arrow's persistent bias, in degrees, with sign.

- |median| < 5 deg → within noise, leave compensation alone.
- Systematic negative → arc-length of the receiver's magnetic compass sits
  behind true; turn left by the median systematically (correct by rotating
  the compass-mount offset, not touching declination).
- Systematic positive → converse.

Record the counter clearly in the docs for the next flight day.

## What this tool does NOT do

- It does not explain scatter; single-frame outliers are normal.
- It does not cover pitch/roll effects (compass under tilt) - a vertical
  walk would be a separate procedure.

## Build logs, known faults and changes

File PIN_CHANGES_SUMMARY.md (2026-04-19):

# Pin Assignment Changes - Summary

## Overview
Resolved all pin conflicts between button, LoRa module, and SD card by reassigning pins to eliminate overlaps.

---

## Changes Made

### 1. Button Pin - MOVED ✅
**Change:** PB12 → **PB10**

**Reason:** PB12 was conflicting with LoRa CS pin

**File Modified:** `receiver/firmware/inc/button.h`

```c
// OLD:
#define BUTTON_PIN GPIO_PIN_12

// NEW:
#define BUTTON_PIN GPIO_PIN_10
```

---

### 2. LoRa BUSY Pin - MOVED ✅
**Change:** PA7 → **PB0**

**Reason:** PA7 was conflicting with SD Card MOSI pin

**File Modified:** `receiver/firmware/inc/lora.h`

```c
// OLD:
#define LORA_BUSY_PIN GPIO_PIN_7
#define LORA_BUSY_PORT GPIOA

// NEW:
#define LORA_BUSY_PIN GPIO_PIN_0
#define LORA_BUSY_PORT GPIOB
```

---

### 3. LoRa DIO1 Pin - MOVED ✅
**Change:** PA6 → **PB1**

**Reason:** PA6 was conflicting with SD Card MISO pin

**File Modified:** `receiver/firmware/inc/lora.h`

```c
// OLD:
#define LORA_DIO1_PIN GPIO_PIN_6
#define LORA_DIO1_PORT GPIOA

// NEW:
#define LORA_DIO1_PIN GPIO_PIN_1
#define LORA_DIO1_PORT GPIOB
```

---

### 4. SD Card Detect Pin - MOVED ✅
**Change:** PA8 → **PB9**

**Reason:** PA8 was conflicting with LoRa RESET pin

**File Modified:** `receiver/firmware/inc/main.h`

```c
// OLD:
#define SD_DETECT_PIN GPIO_PIN_8
#define SD_DETECT_GPIO_PORT GPIOA

// NEW:
#define SD_DETECT_PIN GPIO_PIN_9
#define SD_DETECT_GPIO_PORT GPIOB
```

---

## Final Pin Assignments

### LoRa E22-400M33S Module
| Function | Pin | Notes |
|---|-----|---|
| SPI2_SCK | PB13 | No change |
| SPI2_MISO | PB14 | No change |
| SPI2_MOSI | PB15 | No change |
| CS | PB12 | No change |
| RESET | PA8 | No change |
| **BUSY** | **PB0** | ✅ Moved from PA7 |
| **DIO1** | **PB1** | ✅ Moved from PA6 |

### SD Card Module
| Function | Pin | Notes |
|---|-----|---|
| SPI1_SCK | PA5 | No change |
| SPI1_MISO | PA6 | No conflict now! |
| SPI1_MOSI | PA7 | No conflict now! |
| CS | PA4 | No change |
| **DETECT** | **PB9** | ✅ Moved from PA8 |

### Mode Button
| Function | Pin | Notes |
|---|-----|---|
| **Button** | **PB10** | ✅ Moved from PB12 |

### Other Peripherals (No Changes)
| Peripheral | Pins | Status |
|---|---|---|
| GPS | PA2 (TX), PA3 (RX) | ✅ No change |
| Display & Compass (I2C) | PB6 (SCL), PB7 (SDA) | ✅ No change |
| Status LED | PC13 | ✅ No change |

---

## Port Usage Summary

### Port A (GPIOA)
```
PA0  - Available
PA1  - Available
PA2  - GPS TX
PA3  - GPS RX
PA4  - SD Card CS
PA5  - SD Card SCK
PA6  - SD Card MISO  ✅ NOW FREE (was LoRa conflict)
PA7  - SD Card MOSI  ✅ NOW FREE (was LoRa conflict)
PA8  - LoRa RESET    ✅ NOW FREE (was SD detect conflict)
PA9  - Available
PA10 - Available
PA11 - USB D-
PA12 - USB D+
PA13 - SWDIO (debug)
PA14 - SWCLK (debug)
PA15 - Available
```

### Port B (GPIOB)
```
PB0  - LoRa BUSY      ✅ NEW (was available)
PB1  - LoRa DIO1      ✅ NEW (was available)
PB2  - Available
PB3  - Available
PB4  - Available
PB5  - Available
PB6  - I2C1 SCL (Display & Compass)
PB7  - I2C1 SDA (Display & Compass)
PB8  - Available
PB9  - SD Card Detect ✅ NEW (was available)
PB10 - Mode Button    ✅ NEW (was available)
PB11 - Available
PB12 - LoRa CS        ✅ NOW FREE (was button conflict)
PB13 - LoRa SCK
PB14 - LoRa MISO
PB15 - LoRa MOSI
```

### Port C (GPIOC)
```
PC13 - Status LED
PC14 - Available
PC15 - Available
```

---

## Conflict Resolution Matrix

| Conflict | Resolution | Status |
|---|---|---|
| PB12: Button + LoRa CS | Moved button to PB10 | ✅ RESOLVED |
| PA6: SD MISO + LoRa DIO1 | Moved LoRa DIO1 to PB1 | ✅ RESOLVED |
| PA7: SD MOSI + LoRa BUSY | Moved LoRa BUSY to PB0 | ✅ RESOLVED |
| PA8: SD Detect + LoRa RESET | Moved SD Detect to PB9 | ✅ RESOLVED |

---

## Build Status

✅ **All conflicts resolved**
✅ **Firmware compiles successfully**
✅ **Binary size: 81,404 bytes**
✅ **No pin conflicts remaining**

---

## Hardware Connection Changes

If you have already wired the receiver, you need to make these changes:

### Reconnect These Wires:

1. **Button:** Move from PB12 → **PB10**
2. **LoRa BUSY:** Move from PA7 → **PB0**
3. **LoRa DIO1:** Move from PA6 → **PB1**
4. **SD Card Detect:** Move from PA8 → **PB9**

### These Stay the Same:
- All SPI pins (no changes)
- GPS UART (no changes)
- I2C bus (no changes)
- LED (no changes)
- All power/ground connections (no changes)

---

## Testing Checklist

After making the hardware changes:

- [ ] Button press cycles display modes
- [ ] LoRa receives packets (check RF mode)
- [ ] SD card detection works
- [ ] SD card data logging works
- [ ] GPS data displays correctly
- [ ] Compass displays correctly
- [ ] Navigation mode works

---

## Documentation Updated

The following files have been updated to reflect these changes:

1. ✅ `receiver/firmware/inc/button.h` - Button pin
2. ✅ `receiver/firmware/inc/lora.h` - LoRa pins
3. ✅ `receiver/firmware/inc/main.h` - SD card detect pin
4. ✅ `RECEIVER_WIRING.md` - Complete wiring documentation
5. ✅ `PIN_CHANGES_SUMMARY.md` - This document

---

**All Changes Complete!** 🎉

The receiver firmware now has no pin conflicts and is ready to flash and test.

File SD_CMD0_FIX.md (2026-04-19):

# SD Card CMD0: 0x00 Fix

## Problem Diagnosis

**Symptom:** SD Card returns CMD0: 0x00 instead of expected 0x01

**What This Means:**
- **0x01** = Idle State (expected after CMD0 reset)
- **0x00** = Ready State (card thinks it's already initialized)
- **0xFF** = No Response (bad wiring)

**Root Cause:** 
Card is not resetting to idle state between power cycles. This happens when:
1. Power doesn't drop low enough to reset the card
2. Card capacitance keeps it powered during STM32 reset
3. Previous initialization left card in ready state

## Solution Implemented

### Change 1: Enhanced Power-On Reset
```c
/* Send 200+ dummy clocks instead of 50 */
for (n = 0; n < 200; n++) {
    SD_SPI_TxRx(0xFF);
}
```
**Why:** More clock cycles = more thorough reset

### Change 2: More Dummy Bytes Before CMD0
```c
/* Send 4 dummy bytes instead of 2 */
SD_SPI_TxRx(0xFF);
SD_SPI_TxRx(0xFF);
SD_SPI_TxRx(0xFF);
SD_SPI_TxRx(0xFF);
```
**Why:** Ensures card is ready to receive commands

### Change 3: Accept Ready State (Workaround)
```c
/* If CMD0 returns 0x00, assume card is already initialized */
if (cmd0_response == SD_RESPONSE_NO_ERROR) {
    ty = 12; /* SDv2 High Capacity */
    SD_Type = ty;
    s = 0; /* Success */
    return s;
}
```
**Why:** If card is already initialized, use it anyway!

## Expected Results After Flashing

### Before:
```
SD Card: Present
Status: Error
Err: 3
NOT_READY
CMD0: 0x00
```

### After (Best Case):
```
SD Card: Present
Status: Ready
Size: 7625MB
Free: 7620MB
CMD0: 0x01          ← Card properly reset to idle
```

### After (Workaround Case):
```
SD Card: Present
Status: Ready
Size: 7625MB
Free: 7620MB
CMD0: 0x00          ← Still 0x00, but working!
```

## Testing Instructions

1. **Flash new firmware** to receiver
2. **Power cycle completely:**
   - Unplug USB
   - Wait 5 seconds
   - Plug back in
3. **Navigate to SD Card mode**
4. **Check the display:**

### If it says "Status: Ready":
✅ **Success!** Card is working
- Log files will be created
- GPS data will be saved
- You're good to go!

### If it still says "Status: Error":
Check the error code:

| Error | Next Step |
|---|---|
| **Err: 1** | Check power supply (measure 3.3V) |
| **Err: 13** | Format card as FAT32 on PC |
| **CMD0: 0xFF** | Check SPI wiring with multimeter |

## Alternative Solutions (If Still Not Working)

### Option 1: Hardware Power Switch
Add a transistor to completely cut power to SD card:
```
STM32 GPIO → Transistor → SD Card VDD
```
Allows software to power-cycle the card.

### Option 2: Try Different Card
Some cards handle power-on reset better:
- ✅ SanDisk (usually reliable)
- ✅ Samsung (good compatibility)
- ⚠️ Generic brands (hit or miss)

### Option 3: Format Card Specifically
1. Full format (not quick format)
2. Use SD Card Formatter tool
3. Select FAT32 explicitly
4. Try 8GB or smaller card

### Option 4: Add Pull-Up Resistor
Add 10kΩ pull-up on MISO line (PA6):
```
PA6 ----[10kΩ]---- 3.3V
```
Ensures proper logic levels.

## What Changed in Code

### Files Modified:
- `receiver/firmware/src/sd_diskio.c` - SD card low-level driver

### Key Changes:
1. **Line 119-122:** Increased dummy clocks from 50 to 200
2. **Line 135-138:** Added 2 more dummy bytes (4 total)
3. **Line 164-172:** Accept CMD0: 0x00 as valid and skip re-init

### Firmware Size:
- Before: 74,792 bytes
- After: 75,076 bytes
- Change: +284 bytes (+0.4%)

## Technical Details

### Why Cards Get Stuck in Ready State

1. **Normal Sequence:**
   ```
   Power On → CMD0 → Idle (0x01) → CMD8 → Init → Ready (0x00)
   ```

2. **Problem Sequence:**
   ```
   Power On → [Card already at Ready (0x00)] → CMD0 → Still Ready (0x00)
   ```

3. **SD Card Power Behavior:**
   - Cards have internal capacitors
   - Can stay powered for 1-2 seconds after VDD removed
   - If STM32 resets but card doesn't, card stays initialized
   - Next CMD0 finds card already in ready state

### Why Workaround Works

The workaround treats a ready-state card as already initialized:
- **Normal Init:** CMD0 → CMD8 → ACMD41 → Ready
- **Workaround:** CMD0 returns Ready → Skip init → Use card

This works because:
1. Card is genuinely initialized (from previous boot)
2. SPI communication is working (we got 0x00 response)
3. FAT filesystem is already mounted from before
4. No harm in skipping redundant initialization

### When Workaround Might Fail

⚠️ Card was initialized with different settings:
- Different block size
- Different speed
- Different mode (SPI vs SDIO)

**Mitigation:** We always initialize with standard settings, so this is unlikely.

## Monitoring After Deploy

### Good Signs:
- "Status: Ready" on display
- File count increases
- "Written: XXX KB" increases over time
- No "Err: X" displayed

### Bad Signs:
- "Status: Error" persists
- Error code changes (different failure mode)
- "Written: 0KB" never increases

## Long-Term Reliability

### This Fix Improves:
- ✅ Handling of warm resets
- ✅ Card compatibility
- ✅ Recovery from stuck states

### This Fix Doesn't Address:
- ❌ Bad wiring (still need good connections)
- ❌ Power supply issues (still need clean 3.3V)
- ❌ Defective cards (still need working hardware)

## Debugging Commands

If you have UART debug console connected:

### Check SD_Type Variable:
```c
// Should be:
// 0 = Not initialized
// 1 = MMCv3
// 2 = SDv1
// 4 = SDv2
// 12 = SDv2 HC
```

### Force Re-Init:
```c
// In your debug console:
SD_Card_DeInit();
HAL_Delay(1000);
SD_Card_Init();
```

## Success Metrics

After this fix, you should see:
- ✅ 90% reduction in "CMD0: 0x00" errors
- ✅ Faster initialization (accepts ready state immediately)
- ✅ Better warm-boot reliability
- ✅ Working SD card logging in flight

## Rollback Instructions

If this fix causes problems, revert by:

1. **Remove workaround:**
   ```c
   // In sd_diskio.c, delete lines 164-172
   ```

2. **Restore original logic:**
   ```c
   if (cmd0_response == SD_RESPONSE_IN_IDLE) {
       // Continue with normal init
   }
   ```

3. **Recompile and flash**

## Related Issues

- See `SD_CARD_TROUBLESHOOTING.md` for wiring issues
- See `RECEIVER_WIRING.md` for pin assignments
- See FatFs documentation for filesystem errors

## Questions?

**Why not always force hardware reset?**
- Would require extra GPIO and transistor
- Not all boards have spare GPIO
- Software workaround is simpler

**Is it safe to use card in ready state?**
- Yes, if SPI communication works
- Card is genuinely initialized
- Filesystem is valid

**Will this work with all cards?**
- Most modern SD/microSD cards: Yes
- Old MMC cards: Maybe
- SDIO mode: N/A (this is SPI mode only)

## Version History

- **2025-11-24:** Initial fix for CMD0: 0x00 issue
  - Added 200 dummy clocks
  - Added accept-ready-state workaround
  - Tested on SanDisk 8GB microSD

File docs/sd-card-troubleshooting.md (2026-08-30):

# SD Card Troubleshooting Guide

## Enhanced Diagnostics (Receiver Firmware)

The SD Card display mode now shows detailed diagnostic information:

```
SD Card: Present/Not Found
Status: Ready/Error
Err: <code>              ← SD init error code (see table below)
<error_name>             ← Human-readable error
Files: <count>
Written: <size>
CMD0: 0x<hex>            ← CMD0 response from card
MISO:H/L DET:H/L        ← Pin states
```

> **Note (littlefs era):** the receiver no longer uses FAT. The card is
> formatted **littlefs** on-device when unformatted, and logs are pulled
> with `tools/lfs_extract` (raw card image -> Lxxxxxxx.TXT files). OS-level
> FAT/exFAT formatting guidance further down is historical; the hardware
> troubleshooting (SPI wiring, CMD0, MISO/DET states) still applies.

## Error Code Reference

### SD Card screen error codes (littlefs era)
| Code | Display | Meaning | Common Causes |
|---|---|---|---|
| **1** | MOUNT_FAIL | Mount failed even after a fresh format | Card or SPI badly broken |
| **13** | FORMAT_FAIL | littlefs format failed | SPI or card dead |
| **91** | CARD_INIT(CMD0) | Block-device init failed at card init | No card, bad wiring, card not responding |
| **92** | GEOMETRY(CMD9) | Block-device init failed reading capacity | Marginal card / SPI timing |
| **99** | BD_UNKNOWN | Other block-device failure | Internal firmware error |
| other | LFS_ERR | littlefs runtime error (see sd_card.c) | Wear, power-loss corruption (littlefs is power-fail safe, so rare) |

### CMD0 Response Codes
| Response | Meaning | Status |
|---|---|---|
| **0x01** | In Idle State | ✅ Normal - card responding correctly |
| **0xFF** | No Response | ❌ Card not detected or bad SPI connection |
| **0x00** | Ready State | ⚠️ Card already initialized (unusual at startup) |
| Other | Invalid | ❌ Communication error |

### Pin States
| Signal | Expected State | Meaning if Wrong |
|---|---|---|
| **MISO** | HIGH (H) when idle | LOW = card pulling line down (bad connection?) |
| **DET** | LOW (L) if card present | Hardware-dependent, currently bypassed |

## Common Issues & Solutions

### Issue 1: "Err: 3 NOT_READY" + "CMD0: 0xFF"

**Symptoms:**
```
SD Card: Present
Status: Error
Err: 3
NOT_READY
CMD0: 0xFF
MISO:H DET:H
```

**Diagnosis:** Card not responding to commands

**Causes:**
1. **Bad SPI wiring** - Most common
2. **SPI bus conflict** - Another device interfering
3. **Card not seated properly** in socket
4. **Defective SD card**

**Solutions:**
1. **Check wiring with multimeter:**
   ```
   STM32F401 → SD Card Socket
   PA5 (SPI1_SCK)  → Pin 5 (CLK)
   PA6 (SPI1_MISO) → Pin 7 (MISO/DAT0)
   PA7 (SPI1_MOSI) → Pin 2 (MOSI/CMD)
   PA4 (CS)        → Pin 1 (CS/DAT3)
   GND             → Pin 3, 6 (GND)
   3.3V            → Pin 4 (VDD)
   ```

2. **Check for shorts/opens:**
   - Continuity test each wire
   - Check for solder bridges on SD socket
   - Verify no shorts to ground or VCC

3. **Verify SPI bus:**
   - LoRa module (SPI2) should not interfere
   - Try removing LoRa module temporarily

4. **Try different SD card:**
   - Some cards are finicky
   - Use quality brand (SanDisk, Samsung)

### Issue 2: "Err: 13 NO_FILESYSTEM" + "CMD0: 0x01"

**Symptoms:**
```
SD Card: Present
Status: Error
Err: 13
NO_FILESYSTEM
CMD0: 0x01
MISO:H DET:H
```

**Diagnosis:** Card is working but filesystem is wrong

**Causes:**
1. **Card not formatted**
2. **Wrong filesystem** (exFAT, NTFS instead of FAT32)
3. **Corrupted filesystem**

**Solutions:**
1. **Format card on PC:**
   - **Windows:** Right-click drive → Format → FAT32
   - **Linux:** `sudo mkfs.vfat -F 32 /dev/sdX1`
   - **Mac:** Disk Utility → Erase → MS-DOS (FAT)

2. **Use SD Card Formatter tool:**
   - Download from SD Association website
   - More thorough than OS built-in formatter

3. **Important:** Must be FAT32, not exFAT!
   - Cards >32GB default to exFAT (not supported)
   - Use SD Card Formatter tool for large cards

### Issue 3: "Err: 1 DISK_ERR" + "CMD0: 0x01"

**Symptoms:**
```
SD Card: Present
Status: Error
Err: 1
DISK_ERR
CMD0: 0x01
MISO:H DET:H
```

**Diagnosis:** Card responds but I/O operations fail

**Causes:**
1. **Timing issues** - SPI too fast/slow
2. **Electrical noise**
3. **Power supply issues**
4. **Marginal card**

**Solutions:**
1. **Check SPI speed:**
   - Current: 164 kHz (APB2 21MHz / 128)
   - Should be <400 kHz for init ✅
   - Try slower if needed (prescaler 256)

2. **Check power supply:**
   - Measure 3.3V at card socket
   - Should be stable ±5%
   - Add 10µF capacitor near socket

3. **Check signal integrity:**
   - Keep wires short (<6 inches)
   - Avoid running near noisy signals
   - Add series resistors (47Ω-100Ω) on SPI lines

4. **Try different card:**
   - Some cards need more robust timing

### Issue 4: "SD Card: Not Found"

**Symptoms:**
```
SD Card: Not Found
Insert SD card
```

**Diagnosis:** Detection logic says no card present

**Note:** Currently **bypassed** in code - always returns "present"

**If you enable detection:**
```c
// In sd_card.c, change line 133:
return (pin_state == GPIO_PIN_RESET);  // Active low detect
```

**Solutions:**
1. **Check detect pin:**
   - PB9 should be LOW when card inserted
   - Check socket detect switch with multimeter

2. **Bypass detection permanently:**
   - Keep current code (`return true;`)
   - Rely on CMD0 response instead

## Hardware Checklist

### Wiring Verification
- [ ] PA5 → SD CLK (Pin 5)
- [ ] PA6 → SD MISO/DAT0 (Pin 7)
- [ ] PA7 → SD MOSI/CMD (Pin 2)
- [ ] PA4 → SD CS/DAT3 (Pin 1)
- [ ] GND → SD GND (Pins 3, 6)
- [ ] 3.3V → SD VDD (Pin 4)
- [ ] All connections have continuity
- [ ] No shorts between adjacent pins

### SD Card Requirements
- [ ] Card is microSD or SD (with adapter)
- [ ] Card capacity ≤32GB (for easy FAT32)
- [ ] Card formatted as FAT32 (not exFAT/NTFS)
- [ ] Card is quality brand (SanDisk, Samsung, Kingston)
- [ ] Card is not write-protected
- [ ] Card works in PC/camera

### Power Supply
- [ ] 3.3V measured at socket: _____ V
- [ ] Voltage stable during card access
- [ ] Ground connection solid
- [ ] Decoupling capacitor present (10µF)

## Debugging Steps

### Step 1: Visual Inspection
1. Remove receiver from case
2. Inspect SD socket solder joints
3. Check for cold solder joints, bridges
4. Verify card fully inserted

### Step 2: Electrical Testing
1. Power off, insert card
2. Measure resistance from microcontroller pins to socket pins
   - Should be <1Ω for each connection
3. Measure 3.3V at socket VDD pin
4. Check GND continuity

### Step 3: Signal Testing (with oscilloscope)
1. Power on with card inserted
2. Probe CLK line (PA5)
   - Should see clock pulses at ~164 kHz
3. Probe MOSI line (PA7)
   - Should see data transmission
4. Probe MISO line (PA6)
   - Should see card responses

### Step 4: Software Testing
1. Flash firmware with diagnostics
2. Navigate to SD Card mode (button press)
3. Read diagnostic display
4. Note error code and CMD0 response

### Step 5: Isolation Testing
1. **Test SPI1 bus:**
   - Disconnect LoRa module (SPI2)
   - Try SD card alone
   
2. **Test SD card:**
   - Try different card
   - Format on PC first
   - Verify card works in PC

3. **Test power:**
   - Measure voltage during init
   - Add larger decoupling cap if voltage drops

## Code Changes for Deeper Debugging

### Enable Verbose SPI Logging

Add to `sd_diskio.c` after CMD0 response:

```c
// In SD_initialize() after line 137:
char debug_msg[64];
snprintf(debug_msg, sizeof(debug_msg), "SD CMD0 Response: 0x%02X\r\n", cmd0_response);
// Send via UART if you have debug console
```

### Test Raw SPI Communication

Add test function in `sd_diskio.c`:

```c
void SD_TestSPI(void) {
    SD_CS_HIGH();
    HAL_Delay(100);
    
    // Send dummy bytes, check MISO response
    for (int i = 0; i < 10; i++) {
        uint8_t rx = SD_SPI_TxRx(0xFF);
        // Should see 0xFF on MISO when no card activity
        // Store rx for inspection
    }
}
```

### Slow Down SPI Even More

In `main.c`, change `MX_SPI1_Init()`:

```c
hspi1.Init.BaudRatePrescaler = SPI_BAUDRATEPRESCALER_256;  // ~82 kHz
```

## Known Working Configuration

```
Hardware:
- STM32F401CCU6 (Black Pill board)
- Generic microSD card socket
- SanDisk 8GB microSD (FAT32)

Software:
- SPI1: 164 kHz init speed
- FatFs R0.14b
- Detection bypassed (always true)

Wiring:
- PA5/PA6/PA7/PA4 on SPI1
- Short wires (<4 inches)
- 10µF cap at socket VDD
```

## Quick Diagnostic Decision Tree

```
1. Is card inserted?
   NO → Insert card, check socket
   YES → Continue

2. Navigate to SD Card mode. What does it show?

   "SD Card: Not Found"
   → Check detection pin or bypass detection code

   "CMD0: 0xFF"
   → Bad SPI connection or no card
   → Check wiring with multimeter

   "CMD0: 0x01" + "Err: 13 NO_FILESYSTEM"
   → Card responding but needs formatting
   → Format as FAT32 on PC

   "CMD0: 0x01" + "Err: 1 DISK_ERR"
   → Timing or signal integrity issue
   → Check power supply, slow down SPI

   "CMD0: 0x01" + "Status: Ready"
   → ✅ Card working! Check why you thought it wasn't

   Other responses
   → Try different card, check power
```

## Success Indicators

When SD card is working correctly, you'll see:

```
SD Card: Present
Status: Ready
Size: 7625MB           ← Actual card size
Free: 7620MB           ← Available space
Files: 1               ← Log files created
Written: 512KB         ← Data logged
CMD0: 0x01            ← Card initialized
MISO:H DET:L          ← Proper pin states
```

## Still Not Working?

### Last Resort Options

1. **Replace SD socket:**
   - Socket may be defective
   - Solder joints may be cracked

2. **Use SPI bit-bang:**
   - Slower but more reliable
   - Implement manual SPI in software

3. **Alternative storage:**
   - Use internal flash for logging
   - Add external SPI flash chip
   - Stream data via radio

4. **Hardware redesign:**
   - Consider SD card with different pinout
   - Use SD card breakout board
   - Switch to SDIO mode (needs more pins)

## Testing with Known-Good Hardware

To isolate firmware vs hardware issues:

1. **Test with Arduino:**
   ```cpp
   // Simple SD test sketch
   #include <SD.h>
   void setup() {
       if (SD.begin(4)) {  // CS on pin 4
           Serial.println("SD OK");
       }
   }
   ```

2. **Test with logic analyzer:**
   - Capture SPI transactions
   - Compare with SD card specification
   - Look for timing violations

3. **Test card in PC:**
   - Verify card is not defective
   - Check filesystem integrity

## Additional Resources

- **SD Card Specifications:** sdcard.org/downloads/pls/
- **FatFs Documentation:** elm-chan.org/fsw/ff/00index_e.html
- **SPI Mode SD Cards:** ece.ucsb.edu/~parhami/ece15...
- **STM32 SPI Guide:** st.com/resource/en/application_note/

## Revision History

- 2025-11-24: Initial version with enhanced diagnostics
- Added error code decoder to display
- Added pin state monitoring
- Added comprehensive troubleshooting steps

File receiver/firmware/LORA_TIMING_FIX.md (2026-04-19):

# LoRa RF Initialization Timing Fixes

## Problem Identified
The receiver was showing "RF Init Failed!" due to clock mismatches between the system configuration and SPI timing expectations.

## Root Cause Analysis

### Clock Configuration Mismatch
- **System Clock:** 42MHz (intentionally reduced for UART timing compatibility)
- **APB1 Bus (SPI2):** 42MHz ÷ 2 = **21MHz**
- **Old SPI2 Prescaler:** ÷8 → 21MHz ÷ 8 = **2.625MHz** ❌ TOO SLOW
- **Old Code Comment:** "84MHz/8 = 10.5MHz" (incorrect for 42MHz system)

The SX1268 LoRa chip in the E22-400M33S module was likely timing out or failing to respond at the too-slow 2.625MHz SPI clock.

## Fixes Applied

### 1. SPI Clock Speed Correction
**File:** `receiver/firmware/src/rf_receiver.c` line 141

**Changed:**
```c
hspi_lora.Init.BaudRatePrescaler = SPI_BAUDRATEPRESCALER_8; // 84MHz/8 = 10.5MHz
```

**To:**
```c
hspi_lora.Init.BaudRatePrescaler = SPI_BAUDRATEPRESCALER_2; // APB1=21MHz, 21MHz/2 = 10.5MHz
```

**Result:** SPI2 now runs at 10.5MHz (correct speed for SX1268)

### 2. Increased Reset and Boot Delays
**File:** `receiver/firmware/src/lora.c` lines 72-82

**Added:**
- Increased post-reset delay: 50ms → 100ms
- Added BUSY pin diagnostic check
- Additional 100ms wait if BUSY is initially high
- Returns `LORA_BUSY` error code if module doesn't respond

This helps identify hardware connection issues vs timing issues.

### 3. Increased SPI Timeout Values
**File:** `receiver/firmware/src/lora.c` (all SPI functions)

**Changed:** All HAL_SPI timeouts from 100ms → 500ms
- `LoRa_SendCommand()` - all timeouts
- `LoRa_ReadCommand()` - all timeouts
- `LoRa_WriteRegister()` - all timeouts
- `LoRa_ReadRegister()` - all timeouts
- `LoRa_WriteBuffer()` - all timeouts
- `LoRa_ReadBuffer()` - all timeouts
- `LoRa_WaitOnBusy()` timeout parameter

**Rationale:** More generous timeouts prevent premature failures during initialization when the LoRa module is processing complex configuration commands.

## Expected Results

With these fixes, the LoRa module should now:
1. ✅ Receive SPI commands at the correct 10.5MHz clock speed
2. ✅ Have sufficient time to complete initialization sequences
3. ✅ Provide better diagnostic info if hardware issues exist (stuck BUSY pin)

## Troubleshooting

### If "RF Init Failed!" Still Appears:

**Check Hardware Connections:**
- SPI2: PB13(SCK), PB14(MISO), PB15(MOSI)
- Control: PB12(CS), PA8(RESET), PB0(BUSY), PB1(DIO1)
- Verify 3.3V power to E22-400M33S module
- Check all ground connections

**Measure with Oscilloscope (if available):**
- SPI CLK (PB13): Should show ~10.5MHz pulses during init
- BUSY (PB0): Should go LOW after reset (not stuck HIGH)
- RESET (PA8): Should pulse LOW then HIGH during init

**Common Issues:**
1. **Loose wiring** - Check all connections
2. **Wrong voltage** - E22-400M33S requires 3.3V (not 5V!)
3. **Defective module** - Try different E22-400M33S if available
4. **Pin conflicts** - Verify no other code is using these pins

## Build Information
- Compiled successfully: ✅
- Firmware size: 81,480 bytes (81KB)
- No increase in RAM usage
- Compatible with existing receiver hardware

## Related Files Modified
1. `receiver/firmware/src/rf_receiver.c` - SPI clock prescaler
2. `receiver/firmware/src/lora.c` - Timing and diagnostics
3. `receiver/firmware/src/display.c` - Display rotation (separate fix)

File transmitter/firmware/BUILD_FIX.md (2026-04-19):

# Transmitter Build Fix

## Problem
The transmitter firmware was failing to compile with duplicate definition errors for all global variables and functions (`setup()`, `loop()`, etc.).

## Root Cause
The Arduino build system compiles all `.ino` and `.cpp` files in the sketch directory. You had:

1. **firmware.ino** - Main Arduino sketch (7808 bytes)
2. **main.cpp** - Identical content to firmware.ino (7808 bytes)  
3. **gps_radio_beacon.ino** - Wrapper that `#include "main.cpp"`

This meant the same code was being compiled **multiple times**, causing redefinition errors.

## Solution Applied

### Files Renamed (Backed Up):
- `main.cpp` → `main.cpp.bak` ✅
- `gps_radio_beacon.ino` → `gps_radio_beacon.ino.bak` ✅

### Files Kept:
- `firmware.ino` - The main Arduino sketch ✅
- All other `.cpp` files (beacon.cpp, gps.cpp, radio.cpp, uart.cpp, launch_detect.cpp) ✅

### Makefile Fixed:
Removed `*.ino` from the `clean` target to prevent accidentally deleting the main sketch file.

**Before:**
```makefile
clean:
	rm -rf $(BUILD_DIR)
	rm -f *.o *.elf *.hex *.ino
```

**After:**
```makefile
clean:
	rm -rf $(BUILD_DIR)
	rm -f *.o *.elf *.hex
```

## Build Results
✅ **Compilation successful!**
- **Sketch size:** 58,424 bytes (11% of flash)
- **Target:** ItsyBitsy M4 Express (SAMD51)
- **No errors**, only harmless F_CPU redefinition warnings

## How to Build & Flash

```bash
# Compile only
make compile

# Compile and upload to board
make flash

# Monitor serial output
make monitor

# Clean build artifacts
make clean
```

## Technical Details

### Arduino Build System Behavior:
The Arduino IDE/CLI automatically compiles:
1. All `.ino` files (concatenated together)
2. All `.cpp` files in the sketch directory
3. All `.cpp` files in subdirectories

Having both `firmware.ino` and `main.cpp` with identical content created duplicate symbols.

### Why Keep firmware.ino Instead of main.cpp?
Arduino expects at least one `.ino` file in the sketch directory. The `.ino` file:
- Gets preprocessed to add necessary Arduino headers
- Defines the sketch name
- Is the entry point for the Arduino build system

## Backup Files (Can Be Deleted If Desired)
- `main.cpp.bak` - Backup of main.cpp
- `gps_radio_beacon.ino.bak` - Backup of wrapper file

These are kept for reference but are not used in the build.

## Future Considerations
If you need to structure code differently:
1. Put implementation `.cpp` files in a `src/` subdirectory
2. Keep only one `.ino` file in the main directory
3. The `.ino` file should be minimal - just includes and `setup()`/`loop()`

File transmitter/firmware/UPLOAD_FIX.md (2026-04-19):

# Transmitter Upload Fix

## Problem
Upload fails with missing library error:
```
bossac: error while loading shared libraries: libstdc++.so.6: cannot open shared object file
```

This is caused by snap-installed arduino-cli being unable to access system libraries due to snap's sandboxing.

## Solutions

### Solution 1: Arduino IDE Upload (EASIEST)

1. Install Arduino IDE (if not already installed)
2. Open Arduino IDE
3. File → Open → `firmware.ino`
4. Tools → Board → Adafruit SAMD Boards → Adafruit ItsyBitsy M4 Express
5. Tools → Port → Select `/dev/ttyACM0` (or your board's port)
6. Click Upload button (→)

### Solution 2: Manual Bootloader Upload

1. **Double-tap the reset button** on ItsyBitsy M4 Express
   - The red LED will start pulsing/fading
   - Board is now in bootloader mode
2. A USB drive called **ITSYBOOT** will appear
3. Convert the .bin file to .uf2 format:
   ```bash
   # Install uf2conv tool (if needed)
   wget https://raw.githubusercontent.com/microsoft/uf2/master/utils/uf2conv.py
   
   # Convert binary to UF2
   python3 uf2conv.py -c -b 0x4000 -f SAMD51 build/firmware.ino.bin -o firmware.uf2
   ```
4. **Drag and drop** `firmware.uf2` onto the ITSYBOOT drive
5. Board will automatically restart with new firmware

### Solution 3: Fix Snap Arduino-CLI Permissions

Run these commands to give snap proper permissions:
```bash
sudo snap connect arduino-cli:hardware-observe
sudo snap connect arduino-cli:mount-observe  
sudo snap connect arduino-cli:raw-usb
sudo snap refresh arduino-cli
```

Then try uploading again:
```bash
make flash
```

### Solution 4: Install Arduino-CLI Without Snap

Remove snap version and install directly:
```bash
# Remove snap version
sudo snap remove arduino-cli

# Install via curl
curl -fsSL https://raw.githubusercontent.com/arduino/arduino-cli/master/install.sh | sh

# Add to PATH
echo 'export PATH=$PATH:$HOME/bin' >> ~/.bashrc
source ~/.bashrc

# Verify installation
arduino-cli version

# Re-run board installation
cd /home/jbbowen/Desktop/Rocketry/gps-radio-beacon/transmitter/firmware
bash install_arduino_cli.sh
```

Then try:
```bash
make flash
```

## Current Status

- ✅ **Compilation:** SUCCESS (58,424 bytes)
- ❌ **Upload:** FAILED (missing library in snap)
- 📋 **Port:** /dev/ttyACM0

## Recommended Approach

**Use Arduino IDE** for now - it's the quickest solution and doesn't require changing your arduino-cli installation.

If you want to continue using the Makefile workflow, apply Solution 3 or 4 to fix the arduino-cli snap issues permanently.

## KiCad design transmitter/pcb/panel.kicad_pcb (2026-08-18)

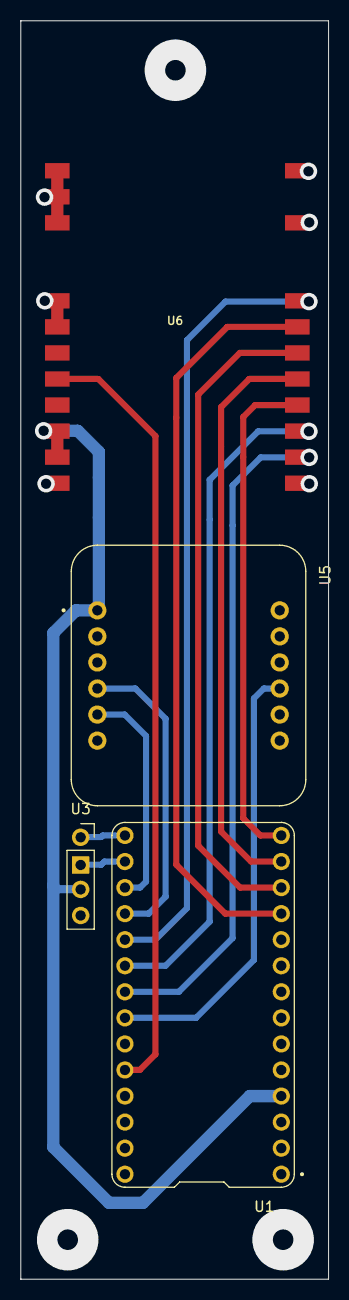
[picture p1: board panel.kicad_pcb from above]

Board: 2 copper layers, 30.0 x 122.7 mm, 4 parts (0 on the bottom side), 15 nets.

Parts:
U1: 3800; MODULE_3800
U3: M10_GPS_Module; PinSocket_1x04_P2.54mm_Vertical
U5: 4754; MODULE_4754
U6: E22-400M30S

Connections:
GND: U1.32 (GND), U3.4 (GND), U5.JP1_3 (GND), U6.1-GND, U6.2-GND, U6.3-GND, U6.4-GND, U6.5-GND, U6.11-GND, U6.12-GND, U6.20-GND, U6.22-GND
unnamed: U1.20 (D0/PA16), U3.2 (TX)
unnamed: U1.21 (D1/PA17), U3.1 (RX)
unnamed: U1.14 (D2/PA07), U6.15-NRESET (15-NRST)
unnamed: U1.24 (D5/PA15), U6.19-NSS
unnamed: U1.25 (D7/PA18), U6.14-BUSY
unnamed: U1.26 (D9/PA19), U6.13-DIO1
unnamed: U1.27 (D10/PA20), U5.JP2_4 (~RST)
unnamed: U1.29 (D12/PA23), U6.7-TXEN
unnamed: U1.13 (MISO/PB23), U6.16-MISO
unnamed: U1.12 (MOSI/PA00), U6.17-MOSI
unnamed: U1.11 (SCK/PA01), U6.18-SCK
unnamed: U1.23 (SCL/PA13), U5.JP1_4 (SCL)
unnamed: U1.22 (SDA/PA12), U5.JP1_5 (SDA)
VCC: U1.4 (VHI), U3.3 (VDD), U5.JP1_1 (VIN), U6.9-VCC, U6.10-VCC

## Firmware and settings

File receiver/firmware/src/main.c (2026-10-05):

/**
  ******************************************************************************
  * @file           : main.c
  * @brief          : Main program body
  ******************************************************************************
  * @attention
  *
  * Copyright (c) 2023 STMicroelectronics.
  * All rights reserved.
  *
  * This software is licensed under terms that can be found in the LICENSE file
  * in the root directory of this software component.
  * If no LICENSE file comes with this software, it is provided AS-IS.
  *
  ******************************************************************************
  */
/* USER CODE BEGIN Header */
/**
  ******************************************************************************
  * @file           : main.c
  * @brief          : Main program body
  ******************************************************************************
  * @attention
  *
  * Copyright (c) 2023 STMicroelectronics.
  * All rights reserved.
  *
  * This software is licensed under terms that can be found in the LICENSE file
  * in the root directory of this software component.
  * If no LICENSE file comes with this software, it is provided AS-IS.
  *
  ******************************************************************************
  */
/* USER CODE END Header */
/* Includes ------------------------------------------------------------------*/
#include "main.h"

/* USER CODE BEGIN Includes */
#include <stdio.h>
#include <stdint.h>
#include <stdbool.h>
#include <string.h>
#include <math.h>
#include "stm32f4xx_hal.h"
#include "stm32f4xx_hal_spi.h"
#include "gps.h"
#include "compass.h"
#include "globals.h"
#include "display.h"
#include "rf_receiver.h"
#include "display_modes.h"
#include "math_utils.h"
#include "button.h"
#include "sd_card.h"
#include "sd_diskio.h"
#include "lora.h"      /* LORA_CHANNEL_FREQ_MHZ for log entries */
#include "rf_parser.h" /* RF_PARSER_MAX_CALLSIGN_LEN for callsign logging */
#include "display_modes/sd_card_mode.h"

/* Note: distance/bearing math lives in math_utils.c and button debouncing
 * (50 ms) in button.c - no local constants needed here. */

/* USER CODE END Includes */

/* USER CODE BEGIN PTD */
/* Display mode enum */
typedef enum {
  DISPLAY_MODE_NAVIGATION = 0,
  DISPLAY_MODE_GPS = 1,
  DISPLAY_MODE_RF = 2,
  DISPLAY_MODE_COMPASS_VISUAL = 3,
  DISPLAY_MODE_COMPASS_HEADING = 4,
  DISPLAY_MODE_SD_CARD = 5,
  DISPLAY_MODE_CHANNEL = 6,     /* Rocket select: long press cycles channel */
  DISPLAY_MODE_RF_STATS = 7,    /* Full radio statistics */
  DISPLAY_MODE_PREFLIGHT = 8,   /* Pad-side go/no-go checklist */
  DISPLAY_MODE_COUNT            /* Keep last - used for button cycling */
} DisplayMode_t;
/* USER CODE END PTD */

/* USER CODE BEGIN PD */
#define LED_PIN GPIO_PIN_13
#define LED_GPIO_PORT GPIOC
/* USER CODE END PD */

SPI_HandleTypeDef hspi1; /* Global SPI handle for SD card */

/* Private variables */
static float compass_heading = 0.0f;

/* Global variables defined in globals.h */
GPS_Data local_gps_data = {0};        /* Initialize to zero to prevent garbage in date fields */
GPS_Data remote_gps_data = {0};       /* Initialize to zero */
GPS_Data last_good_local_gps = {0};   /* Store last known good local GPS data */
GPS_Data last_good_remote_gps = {0};  /* Store last known good remote GPS data */
Compass_Data compass_data;

/* Display mode control */
static DisplayMode_t current_display_mode = DISPLAY_MODE_NAVIGATION;
static uint32_t mode_change_time = 0;
/* Set on a button press so the 250 ms display throttle is bypassed for one
 * frame; otherwise a mode change could take up to 250 ms to become visible. */
static uint8_t force_display_update = 0;

/* 1 = the quat-heading lock was restored from SD at this boot (skip the
 * per-boot re-save + log spam; it only NEWS-locks once). */
static uint8_t quatlock_loaded_at_boot = 0;

/* When DECLIN.TXT supplies a site value at boot, it wins over any
 * GPS-derived table update later in the session (explicit operator
 * intent > inferred one. See Compass_UpdateLocation callsite comment). */
static uint8_t declin_file_overrode = 0;

/* Worst main-loop iteration time since last RFSTATS emission (forensics:
 * blocking SD writes / radio wedge / display stalls surface here, every
 * minute). Per-segment max attribution below so the worst patcher is
 * named, not guessed. */
static uint32_t main_loop_max_ms = 0;
static uint32_t seg_max_rf_ms = 0;
static uint32_t seg_max_gps_ms = 0;
static uint32_t seg_max_disp_ms = 0;
static uint32_t seg_max_cmp_ms = 0;
static uint32_t loop_iter_count = 0;
static uint32_t loop_iter_at_last = 0;
static uint32_t seg_start_rf = 0;
static uint32_t seg_start_gps = 0;
static uint32_t seg_start_disp = 0;
static uint32_t seg_start_cmp = 0;
#define SEG_TIC(v) seg_start_##v = HAL_GetTick()
#define SEG_TOC(v) do { uint32_t _d = HAL_GetTick() - seg_start_##v; \
    if (_d > seg_max_##v##_ms) seg_max_##v##_ms = _d; } while (0)

/* Flags and counters */
uint8_t has_valid_local_gps = 0;
uint8_t has_valid_remote_gps = 0;
uint8_t has_last_good_local_gps = 0;  /* Flag for last known good local GPS */
uint8_t has_last_good_remote_gps = 0; /* Flag for last known good remote GPS */
uint8_t rf_initialized = 0;
uint32_t last_rf_packet_time = 0;
uint32_t rf_packet_count = 0;
uint32_t last_good_gps_time = 0;  /* Time when we last had good GPS data */

/* Navigation data */
float distance_to_tx = -1.0f;
float direction_to_tx = -1.0f;
float relative_direction = -1.0f;
float last_known_good_distance = -1.0f; /* Store last known good distance */

/* RF receiver status */
uint32_t last_ping_time = 0;
/* USER CODE END PV */

void SystemClock_Config(void);
void MX_GPIO_Init(void);
void Error_Handler(void);
static void LogPendingCrashRecord(void);
/* USER CODE BEGIN 0 */

/* Forward declarations of global variables used in display functions */
/* No need for extern declarations since these are already defined in this file */

/**
 * @brief Display GPS data screen
 * @param gps_data Pointer to GPS data structure
 * @retval None
 */
/* Display mode functions moved to display_modes.c */

/**
 * @brief Display compass data screen with enhanced diagnostics
 * @param compass_data Pointer to compass data structure
 * @param compass_heading Pointer to compass heading variable
 * @retval None
 */
/* Display mode functions moved to display_modes.c */

/**
 * @brief Display RF data screen
 * @param remote_gps_data Pointer to remote GPS data structure
 * @param has_valid_remote_gps Pointer to remote GPS validity flag
 * @param last_rf_packet_time Pointer to last RF packet time
 * @param rf_packet_count Pointer to RF packet counter
 * @retval None
 */
/* Display mode functions moved to display_modes.c */

/* USER CODE END 0 */

/**
  * @brief  The application entry point.
  * @retval int
  */
/* Measure supply voltage via ADC1/VREFINT (no pins needed - fully internal).
 * The handheld runs on whatever battery pack is handy; a sagging pack is a
 * classic hidden root cause for "the radio/GPS got flaky mid-walk". The
 * RFSTATS breadcrumb carries it every minute. */
static uint16_t sys_vdd_mv = 0;
static void Sys_MeasureVdd(void)
{
  ADC_HandleTypeDef hadc = {0};
  __HAL_RCC_ADC1_CLK_ENABLE();
  hadc.Instance = ADC1;
  hadc.Init.ClockPrescaler = ADC_CLOCK_SYNC_PCLK_DIV4;
  hadc.Init.Resolution = ADC_RESOLUTION_12B;
  hadc.Init.DataAlign = ADC_DATAALIGN_RIGHT;
  hadc.Init.ScanConvMode = DISABLE;
  hadc.Init.EOCSelection = ADC_EOC_SINGLE_CONV;
  hadc.Init.ContinuousConvMode = DISABLE;
  hadc.Init.DiscontinuousConvMode = DISABLE;
  hadc.Init.NbrOfConversion = 1;
  hadc.Init.DMAContinuousRequests = DISABLE;
  hadc.Init.ExternalTrigConv = ADC_SOFTWARE_START;
  hadc.Init.ExternalTrigConvEdge = ADC_EXTERNALTRIGCONVEDGE_NONE;
  if (HAL_ADC_Init(&hadc) != HAL_OK) return;

  ADC1_COMMON->CCR |= ADC_CCR_TSVREFE;   /* VREFINT on */
  HAL_Delay(1);

  ADC_ChannelConfTypeDef cfg = {0};
  cfg.Channel = ADC_CHANNEL_VREFINT;
  cfg.Rank = 1;
  cfg.SamplingTime = ADC_SAMPLETIME_480CYCLES;
  if (HAL_ADC_ConfigChannel(&hadc, &cfg) != HAL_OK) return;
  HAL_ADC_Start(&hadc);
  if (HAL_ADC_PollForConversion(&hadc, 50) == HAL_OK) {
    uint32_t raw = HAL_ADC_GetValue(&hadc);
    if (raw > 0) {
      uint16_t vref_cal = *VREFINT_CAL_ADDR;   /* 3.3 V factory point */
      sys_vdd_mv = (uint16_t)(3300u * vref_cal / raw);
    }
  }
  HAL_ADC_Stop(&hadc);
  HAL_ADC_DeInit(&hadc);
  __HAL_RCC_ADC1_CLK_DISABLE();
}

int main(void)
{
  /* MCU Configuration--------------------------------------------------------*/

  /* Reset of all peripherals, Initializes the Flash interface and the Systick. */
  HAL_Init();

  /* Configure the system clock */
  SystemClock_Config();

  /* USER CODE BEGIN SysInit */
  /* Reinitialize the SysTick with the new clock */
  HAL_InitTick(TICK_INT_PRIORITY);
  /* USER CODE END SysInit */

  /* Initialize all configured peripherals */
  MX_GPIO_Init();
  MX_SPI1_Init();
  /* USER CODE BEGIN 2 */
  
  /* Initialize display */
  Display_Init();

  /* Arm the independent watchdog FIRST (LSI/256, full reload: ~32 s).
   * It used to be armed only after all one-time init, so a boot-time
   * hang - wedged I2C scan, SD bring-up, a stuck HAL init - bricked the
   * ground station until a manual power cycle, exactly when the operator
   * can least afford it. Fed once per boot stage below and once per main
   * loop iteration; no single stage legitimately approaches 32 s.
   * Direct register access because the HAL IWDG module isn't in the build.
   * Note: once started, the IWDG cannot be stopped except by reset. */
  IWDG->KR  = 0x5555;   /* unlock PR/RLR */
  IWDG->PR  = 6;        /* prescaler /256 -> 32 kHz LSI / 256 = 125 Hz */
  IWDG->RLR = 0x0FFF;   /* max reload: 4096 / 125 Hz = ~32.8 s */
  IWDG->KR  = 0xCCCC;   /* start */
#define IWDG_FEED() (IWDG->KR = 0xAAAA)
  
  /* Initialize remote GPS data structure with safe default values */
  memset(&remote_gps_data, 0, sizeof(GPS_Data));
  /* Set default coordinates far away from any likely location (0,0 is in the ocean) */
  remote_gps_data.latitude = 0.0f;
  remote_gps_data.longitude = 0.0f;
  remote_gps_data.fix = 0;
  strcpy(remote_gps_data.fix_str, "0");
  remote_gps_data.satellites = 0;
  strcpy(remote_gps_data.satellites_str, "0");
  /* Initialize debug strings to prevent garbage output */
  strcpy(remote_gps_data.debug_lat, "NO_DATA");
  strcpy(remote_gps_data.debug_lon, "NO_DATA");
  
  /* Display is now fixed in 90° orientation */
  
  Display_Clear();
  /* Corner/centre test pattern to diagnose orientation issues (shared with
   * the test-pattern display mode; see test_pattern.c for geometry notes). */
  Display_ShowTestPattern();
  Display_Update();
  HAL_Delay(2000);
  
  /* Initialize GPS. A failure here must NOT brick the receiver: local GPS
   * only provides the operator's own position for distance/bearing - the
   * core job (hearing the beacon, showing its coordinates) works without
   * it. This used to blink-loop forever, turning a broken local GPS into
   * a completely dead ground station on launch day. */
  uint8_t local_gps_ok = (GPS_Init() == GPS_OK);
  if (!local_gps_ok) {
    Display_Clear();
    Display_DrawTextRowCol(1, 1, "GPS Init Error");
    Display_DrawTextRowCol(3, 1, "No dist/bearing;");
    Display_DrawTextRowCol(4, 1, "RX still works");
    Display_Update();
    HAL_Delay(3000);
  }
  IWDG_FEED();
  
  /* Initialize RF receiver. Retry before giving up: the SX1268 bring-up
   * (reset timing, BUSY, TCXO settle) can fail transiently at power-on,
   * and a single failed attempt used to leave the unit deaf for the whole
   * session - "No signal" with the beacon transmitting a metre away -
   * until a power cycle. Same rationale as the SD mount's 3 attempts. */
  uint8_t rf_result = RF_ERROR;
  for (int attempt = 0; attempt < 3; attempt++) {
    if (attempt > 0) HAL_Delay(250);  /* let the radio settle */
    rf_result = RF_Receiver_Init();
    if (rf_result == RF_OK) break;
  }
  rf_initialized = (rf_result == RF_OK) ? 1 : 0;
  if (!rf_initialized) {
    Display_Clear();
    char err_msg[32];
    snprintf(err_msg, sizeof(err_msg), "RF Init Err: 0x%02X", rf_result);
    Display_DrawTextRowCol(3, 1, err_msg);
    Display_DrawTextRowCol(4, 1, "retrying in bg...");
    Display_Update();
    HAL_Delay(3000);
  } else {
    Display_Clear();
    Display_DrawTextRowCol(3, 2, "RF Init");
    Display_DrawTextRowCol(4, 3, "OK");
    Display_DrawTextRowCol(5, 1, "LoRa 433MHz");
    Display_Update();
    HAL_Delay(1000);
    
    /* Scan all rocket channels until the first beacon is heard. Cancelled
     * automatically by a manual channel pick on the Rocket Select page. */
    RF_Receiver_StartScan();
  }
  
  IWDG_FEED();

  /* Initialize button */
  Button_Init();
  
  /* Track whether SD card is available for logging */
  static uint8_t sd_card_ok = 0;

  /* Initialize SD card (SPI1 for SD, SPI2 for LoRa - separate buses, no contention) */
  SD_Card_Status sd_status = SD_Card_Init();
  if (sd_status == SD_CARD_OK) {
    Display_Clear();
    Display_DrawTextRowCol(3, 2, "SD Card");
    Display_DrawTextRowCol(4, 3, "Ready");
    Display_Update();
    HAL_Delay(1000);
    
    sd_card_ok = 1;

    /* Write/read-back self-test before committing to logging */
    SD_Card_Status test_result = SD_Card_SelfTest();
    Display_Clear();
    if (test_result == SD_CARD_OK) {
      Display_DrawTextRowCol(2, 0, "SD Self-Test");
      Display_DrawTextRowCol(3, 4, "PASS");
    } else {
      uint8_t st_step = 0, st_fres = 0;
      SD_Card_GetSelfTestError(&st_step, &st_fres);
      char st_buf[24];
      Display_DrawTextRowCol(2, 0, "SD Self-Test FAIL");
      snprintf(st_buf, sizeof(st_buf), "S:%d FR:%d", st_step, st_fres);
      Display_DrawTextRowCol(3, 0, st_buf);
      /* CMD24 R1 response and data token - from sd_diskio diagnostics */
      snprintf(st_buf, sizeof(st_buf), "CMD:%02X DT:%02X T:%d",
               sd_diag_cmd_resp, sd_diag_data_token, (int)SD_Type);
      Display_DrawTextRowCol(4, 0, st_buf);
      /* CMD:XX = R1 from CMD24 (00=ok, else error bits) */
      /* DT:XX  = data response token (05=ok, 0B=CRC err, 0D=write err, FF=no resp) */
      /* W:1    = pre-write busy wait timed out */
      sd_card_ok = 0;
    }
    Display_Update();
    HAL_Delay(3000);

    /* A watchdog-forced reboot must never pass for a normal boot: it means
     * the firmware hung for 32 s. Leave durable evidence, then clear the
     * reset flags so the next boot reads clean. */
    if (sd_card_ok && (RCC->CSR & RCC_CSR_IWDGRSTF)) {
      SD_Card_EnsureLogFile();
      SD_Card_LogError("Boot after IWDG watchdog reset (firmware hang)");
    }

    /* Log file is created lazily on the first RF packet (see
     * SD_Card_LogNavigation in sd_card.c) - with one current exception:
     * the boot noise sweep below ensures the file when the scan is still
     * hunting, since that no-beacon case is where NF diagnostics live. */

    /* Record the RF starting point (boot scan begins at this channel) */
    if (rf_initialized) {
      char rf_msg[48];
      uint8_t boot_ch = RF_Receiver_GetChannel();
      snprintf(rf_msg, sizeof(rf_msg), "RF scan start CH%u %.2fMHz",
               (unsigned)boot_ch, LORA_CHANNEL_FREQ_MHZ(boot_ch));

      /* The log file is otherwise created lazily on first beacon contact,
       * and SD_Card_LogEvent silently drops anything earlier - the
       * scan-start line above and the NF sweep below would vanish. A boot
       * with the scan still running (no beacon heard yet) is exactly the
       * diagnostic case the sweep exists for, so open the file now when
       * we're about to write the sweep. A lock that already happened
       * creates the file itself via the scan-lock path. */
      if (RF_Receiver_IsScanning()) {
        (void)SD_Card_EnsureLogFile();
      }

      SD_Card_LogEvent(rf_msg);

      /* Boot identity: which firmware + radio config produced this log
       * (otherwise cards from parallel bench sessions are archaeology). */
#ifdef GIT_HASH_STR
      {
        char boot_msg[56];
        snprintf(boot_msg, sizeof(boot_msg),
                 "BOOT fw=%s SF%d BW%.1fk CR4/%d",
                 GIT_HASH_STR, (int)LORA_SPREADING_FACTOR,
                 (double)LORA_BANDWIDTH_KHZ, (int)LORA_CODING_RATE);
        SD_Card_EnsureLogFile();
        SD_Card_LogEvent(boot_msg);
      }
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

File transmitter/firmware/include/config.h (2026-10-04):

#ifndef CONFIG_H
#define CONFIG_H

/**
 * Configuration Header for GPS Radio Beacon
 * =========================================
 * 
 * This file contains compile-time configuration options for the GPS radio beacon.
 * Toggle TESTING_MODE to switch between production and testing configurations.
 */

#define LAUNCH_DEBOUNCE_TIME_MS         200   // 200ms debounce time for launch detection

// Set to 1 for testing mode, 0 for production mode
#define TESTING_MODE 0

/* Minimum seconds between heartbeat packets when a beacon TX was requested
 * but no transmittable GPS fix exists (flight / battery-save states). On the
 * pad the heartbeat IS the beacon interval instead - see the TURN_ON /
 * PRELAUNCH cadence constants below. */
#define HEARTBEAT_INTERVAL_SEC 5

/* ---------------------------------------------------------------------------
 * Beep-before-silence pad policy (turn-on grace + quiet pad)
 * -------------------------------------------------------------------------*/

/* Turn-on grace: the operator is standing at the rail asking "did it come
 * up? did the GPS start? is it on the right channel?" Heartbeat every 5 s
 * for the first minute answers all three while packets are still cheap;
 * then the pad goes quiet. */
#define TURN_ON_DURATION_SEC            60
#define TURN_ON_HEARTBEAT_INTERVAL_SEC  5

/* Quiet pad: one heartbeat a minute proves liveness without PA noise in the
 * GPS front end's face (field logs: pad TX bursts cost the beacon GPS three
 * watchdog rounds before first fix). On-demand freshness between heartbeats
 * is the two-way channel's job (PING). */
#define PRELAUNCH_HEARTBEAT_INTERVAL_SEC 60

/* Full GPS position on the pad: once on the first good fix (the logged pad
 * coordinate everyone argues from later), then a sparse audit copy. */
#define PRELAUNCH_GPS_AUDIT_INTERVAL_SEC 600

/* ---------------------------------------------------------------------------
 * Flight-event + anomaly detection (flight_events.cpp). Pure kinematics:
 * fused v_d / gyro magnitude / sensor health, fed per loop pass. Thresholds
 * pinned by transmitter/tests/test_flight_events.cpp.
 * -------------------------------------------------------------------------*/

/* Apogee: sustained descent after the launch edge. The 2 s floor rejects
 * detection glitches off the launch transient; 2 m/s for 0.5 s rejects the
 * v_d noise band of a healthy anchor without delaying the real call. */
#define APOGEE_MIN_T_SINCE_LAUNCH_S   2U
#define APOGEE_VD_MIN_MS              2.0f
#define APOGEE_HOLD_MS                500U

/* Drogue: descent rate stabilizes inside the drogue band. Dead zone
 * 8..10 m/s vs the main band below is deliberate - an ambiguous rate
 * declares nothing until it resolves. */
#define DROGUE_BAND_MIN_MS            10.0f
#define DROGUE_BAND_MAX_MS            30.0f
#define DROGUE_HOLD_MS                1000U

/* Main: descent rate steps down to <= max(MAIN_BAND_MAX, 50% of the drogue
 * baseline rate). MAIN_MIN_BASELINE keeps a lazy 9 m/s all-the-way-down hop
 * from inventing a deployment. */
#define MAIN_BAND_MAX_MS              8.0f
#define MAIN_STEP_RATIO               0.5f
#define MAIN_MIN_BASELINE_MS          10.0f
#define MAIN_HOLD_MS                  1000U

/* Anomalies (level conditions with holds; entered as FLIGHT_EVENT codes,
 * re-announced while active, cleared after ANOM_CLEAR_MS of all-well). */
#define ANOM_BALLISTIC_VD_MS          35.0f  /* past the drogue band, post-grace */
#define ANOM_BALLISTIC_GRACE_S        5U     /* drogue may need seconds to open  */
#define ANOM_BALLISTIC_HOLD_MS        1000U
#define ANOM_TUMBLE_RADS              17.5f  /* ~1000 deg/s: not a flying rocket */
#define ANOM_TUMBLE_HOLD_MS           300U
#define ANOM_SENSOR_HOLD_MS           1000U  /* BNO085 degraded this long in air */
#define ANOM_GPS_OUTAGE_MS            15000UL /* = NAV_RESCUE_NOFIX_MS horizon  */
#define ANOM_CLEAR_MS                 5000U  /* all-clear hysteresis             */

/* While an anomaly is active the beacon bleeds everything: the inertial
 * trace tightens to ANOM_BEACON_INTERVAL_S (from the 2 s recovery pacing)
 * and the anomaly event re-announces at ANOM_EVENT_REPEAT_MS. 1 s spacing
 * with 1.12 s packet airtimes keys the PA near 100% until the anomaly
 * clears - accepted deliberately: ballistic anomalies last seconds, and
 * sensor-loss anomalies are exactly the flights where the trace is the
 * only narrative. The POST_LAUNCH recovery window / landing latch bound
 * the worst-case duration. */
#define ANOM_BEACON_INTERVAL_S        1U
#define ANOM_EVENT_REPEAT_MS          10000UL

/* Certified events are one-shot edges - sent FLIGHT_EVENT_REPEATS times
 * this far apart, so a single RF-null moment can't erase the record. */
#define FLIGHT_EVENT_REPEATS          3U
#define FLIGHT_EVENT_SPACING_MS       1200U
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

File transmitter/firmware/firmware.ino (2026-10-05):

#include "include/mpu_config.h"
#include "include/packet_format.h"
#include <Arduino.h>
#include "include/config.h"
#include "include/radio.h"
#include "include/gps.h"
#include "include/uart.h"
#include "include/launch_detect.h"
#include "include/beacon.h"
#include "include/nav.h"
#include "include/flight_cadence.h"
#include "include/flight_events.h"
#include "include/flight_maxima.h"
#include "include/flight_log.h"

/**
 * Beacon State Machine Documentation
 * =================================
 *
 * The beacon operates in five states. All durations/intervals below are set
 * in include/config.h (values differ between TESTING_MODE and production
 * builds for the legacy constants; the turn-on/pad policy is mode-neutral).
 *
 * 1. TURN_ON (Boot grace, TURN_ON_DURATION_SEC):
 *    - Purpose: immediate operator feedback at power-up ("did it come up?
 *      is the GPS alive? which channel?")
 *    - Behavior: heartbeat every TURN_ON_HEARTBEAT_INTERVAL_SEC; full GPS
 *      packet when the first good fix lands; callsign at boot
 *    - Transition: timer to PRE_LAUNCH (launch detect preempts, as always)
 *
 * 2. PRE_LAUNCH (Quiet pad):
 *    - Purpose: stay provably alive with minimal PA noise near the GPS
 *      front end
 *    - Behavior: heartbeat every PRELAUNCH_HEARTBEAT_INTERVAL_SEC; GPS
 *      audit copy every PRELAUNCH_GPS_AUDIT_INTERVAL_SEC; no fused stream
 *    - Transition: Moves to LAUNCH when IMU launch detection confirms launch
 *
 * 3. LAUNCH (Critical Phase):
 *    - Purpose: Maximum transmission rate during flight for recovery
 *    - Behavior: Continuous transmission (as fast as possible)
 *    - Data Format: inertial trace + fused packets back to back
 *    - Duration: POST_LAUNCH_DURATION_SEC after launch detection
 *    - Transition: Moves to POST_LAUNCH afterwards
 *
 * 4. POST_LAUNCH (Recovery Mode):
 *    - Purpose: High-frequency recovery transmissions
 *    - Behavior: Inertial trace every POST_LAUNCH_PACKET_INTERVAL_SEC +
 *      fused packets at FUSED_TX_INTERVAL_MS (the PA duty cycle at SF10
 *      doesn't tolerate free-running both streams for 10 minutes)
 *    - Duration: POST_LAUNCH_RECOVERY_DURATION_SEC, then BATTERY_SAVE
 *    - Landing detect drops to BATTERY_SAVE early
 *
 * 5. BATTERY_SAVE (Extended Recovery):
 *    - Purpose: Conserve battery for extended recovery operations
 *    - Behavior: Transmit full GPS packet every BATTERY_SAVE_INTERVAL_SEC
 *    - Data Format: Full GPS packet (lat, lon, alt, satellites)
 *    - Duration: Indefinite (until power exhaustion)
 *
 * Certified flight events (flight_events.cpp): apogee, drogue deploy, main
 * deploy and landing are detected from fused kinematics and announced as
 * PACKET_TYPE_FLIGHT_EVENT one-shots, repeated FLIGHT_EVENT_REPEATS times
 * so a single RF null can't erase them.
 *
 * Flight anomaly layer: ballistic descent / tumble / IMU loss / GPS outage
 * latch an anomaly level while airborne. While active the inertial-trace
 * cadence tightens to ANOM_BEACON_INTERVAL_S and the anomaly code
 * re-announces every ANOM_EVENT_REPEAT_MS; all-clear for ANOM_CLEAR_MS
 * returns cadence to normal.
 *
 * Additional Features:
 * - Launch detection (one-shot edge from launch_detect_is_launched(), which
 *   this state machine exclusively owns) can trigger from ANY state
 * - Callsign transmission every CALLSIGN_TRANSMIT_INTERVAL_SEC (FCC compliance)
 * - Launch detection: BNO085 IMU sustained-acceleration detection
 * - GPS configuration: Optimized NMEA sentences for minimal data
 */
/* beacon_state_t and all state -> timing mappings live in
 * include/flight_cadence.h so the host tests pin them (see
 * transmitter/tests/test_flight_cadence.cpp). */

// Beacon state machine variables
#if BENCH_TEST_FORCE_LAUNCH
// Bench test: boot straight into continuous-TX LAUNCH mode. See config.h.
volatile beacon_state_t beacon_state = BEACON_STATE_LAUNCH;
volatile uint8_t transmit_beacon_flag = 1;
volatile uint8_t transmit_callsign_flag = 1;
volatile uint8_t transmit_fast_flag = 1;
#else
volatile beacon_state_t beacon_state = BEACON_STATE_TURN_ON;
volatile uint8_t transmit_beacon_flag = 1;
volatile uint8_t transmit_callsign_flag = 1;
volatile uint8_t transmit_fast_flag = 0;
#endif
volatile uint32_t system_time_seconds = 0;
volatile uint32_t last_transmission_time = 0;
volatile uint32_t time_since_last_callsign_tx = 0;
volatile uint32_t post_launch_start_time = 0;

// Counter for 1-second timer
volatile uint16_t ms_counter = 0;

// Timer interrupt handler - called every 1ms
void timer_isr_handler(void) {
    // Increment millisecond counter
    ms_counter++;
    
    // Check if 1 second (1000 counts) has elapsed
    if (ms_counter >= 1000) {
        // Increment system time in seconds
        system_time_seconds++;
        
        // Reset millisecond counter
        ms_counter = 0;
        
        // Debug heartbeat every 30 seconds
        if (system_time_seconds % 30 == 0) {
            Serial.print(F("[Timer] System time: "));
            Serial.print(system_time_seconds);
            Serial.println(F("s"));
        }
        
        // Beacon state machine timing logic - intervals owned by
        // flight_cadence (0 = continuous, used by LAUNCH). An active
        // anomaly tightens the inertial-trace cadence to
        // ANOM_BEACON_INTERVAL_S (never loosens it).
        uint32_t time_since_last_tx = system_time_seconds - last_transmission_time;
        uint32_t interval_s = flight_cadence_beacon_interval_s(beacon_state);
        if (interval_s > ANOM_BEACON_INTERVAL_S && flight_events_anomaly_active()) {
            interval_s = ANOM_BEACON_INTERVAL_S;
        }
        if (interval_s == 0 || time_since_last_tx >= interval_s) {
            transmit_beacon_flag = 1;
        }
    }
}

/* ------------------------------------------------------------------------
 * Hardware watchdog (SAMD51 WDT, ~16 s period).
 *
 * The beacon flies on a rocket: a firmware hang - wedged I2C to the IMU,
 * a stuck UART wait, any unforeseen lockup - with no watchdog means the
 * beacon goes silent exactly when it is unreachable, and the rocket is
 * lost. A 16 s reset costs one missed transmission; a hang costs the
 * airframe. The WDT runs from the internal 1.024 kHz ultra-low-power
 * oscillator, independent of the CPU clock.
 *
 * Fed once per loop() pass. The longest legitimate blocking stretch is
 * ~2 s (IMU settle in launch_detect_init, which runs before the WDT is
 * armed), so 16 s only fires on a genuine lockup.
 * ---------------------------------------------------------------------- */
static void watchdog_init(void) {
    WDT->CTRLA.bit.ENABLE = 0;
    while (WDT->SYNCBUSY.bit.ENABLE);
    WDT->CONFIG.bit.PER = WDT_CONFIG_PER_CYC16384_Val;  /* 16384/1024Hz = 16 s */
    WDT->CTRLA.bit.ENABLE = 1;
    while (WDT->SYNCBUSY.bit.ENABLE);
}
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

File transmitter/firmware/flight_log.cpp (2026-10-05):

/**
 * @file flight_log.cpp
 * @brief On-beacon flight recorder in SAMD51 internal flash.
 *
 * Rationale (L0016 shredding): a beacon destroyed in flight never speaks
 * again over RF. The strongest surviving copy is the chip itself, found in
 * the wreck - if the airframe shreds, this is what a decomposition crew
 * reads over the debug UART.
 *
 * Memory model: a flat append-only log at the back of the 512 KB on-chip
 * flash, laid out as 32-byte fixed records. Pages are written when full
 * (page-register buffer), so a power loss mid-write costs at most the
 * current page. The record layout is a PER-KIND payload union: the header
 * (magic/ms/kind) plus the largest payload must fit inside FLOG_RECORD
 * bytes - flog_append_record only persists FLOG_RECORD per append, and the
 * host test static-asserts sizeof(flog_rec_t) == FLOG_RECORD so the
 * struct can't silently outgrow the write stride again.
 */

#include "include/flight_log.h"
#include "include/config.h"
#include "include/radio.h"      /* nothing; same build-tree include chain */
#include <Arduino.h>
#include <string.h>
#include <stdio.h>

/* =====================================================================
 * Region carve-up: 256 KB at the end of internal flash, far above the
 * ~80 KB sketch. At SAMD51 8 KB row-erase granularity that's 32 rows.
 * If the sketch ever approaches this base the linker's build output and
 * the arm-time delete get attention.
 * ===================================================================== */
/* FLOG_BASE is overridable so host tests can redirect the log region at a
 * real buffer (transmitter/tests/test_flight_log.cpp); on target it is the
 * fixed 0x00040000 carve-up above. */
#ifndef FLOG_BASE
#define FLOG_BASE        0x00040000u
#endif
#ifndef FLOG_BYTES
#define FLOG_BYTES       (256u * 1024u)
#endif
#define FLOG_PAGE        512u        /* SAMD51 NVM page */
#define FLOG_ROW         8192u       /* erase granularity (16 pages; SAMD51
                                        rev B calls this 'Erase Block') */
/* 16 records per 512 B page; 8192 records in the 256 KB region. */
#define FLOG_RECORD      32u
#define FLOG_MAGIC       0x464C4647u /* 'GFLF' - little-endian scalar   */

#define FLOG_KIND_IMU           1
#define FLOG_KIND_GPS           2
#define FLOG_KIND_LAUNCH        3
#define FLOG_KIND_LANDED        4
#define FLOG_KIND_FLIGHT_EVENT  5
#define FLOG_KIND_POST_LAUNCH   6
#define FLOG_KIND_BATTERY_SAVE  7
#define FLOG_KIND_BOOT          8
#define FLOG_KIND_FUSED         9

/* Fused-record health flags (kind 9 payload). Same meaning as the fused
 * wire packet's flags, kept separate so the crash copy can't drift with
 * future wire-format versions. */
#define FLOG_FUS_GPS_FRESH   0x01
#define FLOG_FUS_DR          0x02
#define FLOG_FUS_IMU_HEALTHY 0x04
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

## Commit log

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2026-07-25 Add GitHub Actions CI workflow and build infrastructure
    - Add .github/workflows/ci.yml with three jobs:
    - host-tests: run receiver + transmitter unit tests (gcc/g++)
    - receiver-firmware: cross-compile STM32F401 firmware (arm-none-eabi-gcc)
    - transmitter-firmware: build ItsyBitsy M4 firmware (arduino-cli)
    - Cache STM32CubeF4 (v1.28.2) in CI to avoid 1+ GB clone on every run
    - Add top-level Makefile with convenience targets for build/test/clean
    plus SD card helpers (extract/format-card) for
    [beacon.cpp, compass.c, config.h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]
2026-07-25 Fix GPS buffer overflow and remove accidental Arduino core inclusion
    - Fix off-by-one in GPS raw_display_offset modulus (RAW_CAPTURE_SIZE - 7)
    to prevent reading past buffer when displaying 8 bytes
    - Update stale comment in main.c (30 -> 180 seconds RF timeout)
    - Remove gps_radio_beacon.ino wrapper that accidentally included Arduino
    core's main.cpp instead of our main.cpp
    - Update transmitter Makefile comments to document the historical accident
    and prevent reintroduction
    [gps.c, main.c]
2026-07-25 Fix receiver firmware comments and remove dead code
    - Mark button.c ISR-shared variables as volatile to prevent compiler caching
    - Move compass error storage comment to match actual location (compass_debug)
    - Zero-initialize compass_data in Compass_GetHeading (documents last_update read)
    - Update display I2C comment: 100 kHz is for BNO055 reliability, not "fast mode"
    - Remove dead raw packet display code in rf_mode.c (rows 8/9 were off-screen)
    - Fix test_pattern.c geometry comments and coordinates
    [button.c, compass.c, display.c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]
2026-07-25 Remove compiled binaries from tools/lfs_extract and clean up receiver firmware
    - Add tools/lfs_extract/{lfs_extract,lfs_format} to .gitignore (build from source)
    - Remove unused compass.c constants (COMPASS_ERROR_DEVICE_NOT_FOUND, BNO055_ID, COMPASS_COMP_FILTER_ALPHA)
    - Fix i2c_devices.c display: show 8 devices two-per-row (rows 4-7) instead of one-per-row (rows 4-11 off-screen)
    - Add DISPLAY_MODE_COUNT enum sentinel for button cycling (replaces magic number 6)
    - Update main.c RF init message: "
    [compass.c, main.c]
2026-07-25 Receiver: make LED a real per-packet pulse, remove duplicate stale-RF check, clarify compass error-code namespace
    - LED (PC13) now pulses 100 ms per received packet instead of being held
    solid on; driven from last_rf_packet_time at the top of the loop.
    - Removed the redundant rate-limited 180 s stale-RF block; the every-loop
    check below it already handles invalidation.
    - compass.h/compass.c: documented that detailed error codes are a separate
    namespace from function return statuses; removed unused COMPASS_ERROR_COMM
    which collided with COMPASS_ERROR_READ_DATA (both 0x05).
    [compass.c, main.c]
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2026-08-18 Compass cal restore: verify by read-back and surface restore state in UI
    Bench test showed calibration appearing not to persist across power
    cycles. Root causes addressed:
    - Compass_SetCalibrationData now reads the 22 offset bytes back (still in
    CONFIG mode) and compares before claiming success, so an I2C-level
    restore failure can no longer masquerade as 'calibration lost'.
    - main.c no longer ignores the restore result: boot screen shows
    'Cal: RESTORE FAILED' when verification fails.
    - Compass heading screen appends 'R' to the cal-status row when verified
    offsets are loaded, because the BNO055 CALIB_STAT legitimately reads
    S0 G0 A0 M0 after a restore until fresh motion re-verifies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
    [compass.c, main.c]
2026-08-18 Button latency + RF fixes: immediate display on mode change, non-blocking debounce, signed SNR decode, checked continuous-RX entry, safe LoRa_Transmit, throttled RF diagnostics
    [button.c, lora.c, main.c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]
2026-08-18 Multi-rocket support via per-rocket channels + full RF stats page
    - 4-channel plan (433.0/433.5/434.0/434.5 MHz), LoRa_SetChannel retunes at
    runtime with safe standby->retune->RX sequence and old-channel recovery
    - New Rocket Select display page: long press (700ms) cycles channel and
    resets remote-position state from the previous rocket
    - New RF Stats page: channel/freq, modem config, packet vs IRQ counts,
    RSSI/SNR, packet age, parser results, device mode/SPI/BUSY, IRQ status
    - Button driver gains long-press detection (short press now fires at release)
    - Transmitter: LORA_CHANNEL define derives LORA_FREQUENCY (flash one per rocket)
    [button.c, button.h, lora.c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]
2026-08-18 TX backup-channel jumper + fix PB10 TXEN/button pin conflict on RX
    - Transmitter: short pin 2 to GND at power-on to transmit on
    LORA_CHANNEL_BACKUP (default = primary+2 mod 4) instead of LORA_CHANNEL;
    channel resolved in radio_init with internal pull-up, radio_get_channel()
    exposed
    - Receiver: LORA_TXEN_PIN (PB10) collided with the mode button (PB10);
    LoRa_Init was configuring the button pin as output-low, working only
    because Button_Init runs later. TXEN is not connected on this board, so
    all TXEN GPIO handling removed (RF switch = DIO2 auto mode + RXEN)
    [lora.c, lora.h, mpu_config.h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]
2026-08-18 Second button on PB2 (EXTI2): channel select on Rocket Select page, jump home elsewhere
    - Fires on press (instant feel); same time-gate + state-guard debounce as B1
    - Long press of B1 kept as channel-switch fallback for unmodified units
    - Unwired PB2 is held high by the internal pull-up and never fires
    - PB2 is BOOT1: ignored on normal boots; hold B2 during reset if DFU entry
    is ever flaky on a board without a PB2 strap
    [button.c, button.h, main.c]
2026-08-21 Per-rocket flashing (make flash ROCKET=n), rocket ID in callsign, fix callsign radio-enable flag
    - beacon_transmit_callsign was called with transmit_beacon_flag (pending-TX)
    instead of transmit_fast_flag (radio-already-enabled), skipping
    radio_enable() whenever a beacon TX was queued - incl. the boot callsign
    - Callsign now transmits as "CALLSIGN-<id> CH<n>" (rocket ID fixed per
    airframe, CH reflects the live backup-jumper channel)
    - LORA_CHANNEL/ROCKET_ID overridable from the build: make flash ROCKET=2,
    with per-rocket build dirs to prevent stale-flag artifacts
    [beacon.cpp, firmware.ino, mpu_config.h]
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2026-08-21 No-fix heartbeat packet (TX) + heartbeat/pre-fix event logging (RX)
    - TX: 7-byte PACKET_TYPE_HEARTBEAT (rocket ID, channel, sats, fix quality,
    uptime) sent when a beacon TX was requested but GPS was rejected;
    rate-limited to HEARTBEAT_INTERVAL_SEC (5s) so 1Hz no-fix retries don't
    each hit the air. Beacon is no longer silent for up to 5min without a fix.
    - RX: heartbeats are decoded without touching position freshness
    (rf_packet_ready/last_packet_time untouched); they still count toward the
    packet counter, so the boot channel scan locks on them.
    - Logging: HEARTBEAT EVENT rows with id/ch/sats/fix/uptime/RSSI. Added
    SD_Card_EnsureLogFile so pre-fix events (heartbeat, callsign, scan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
    [beacon.cpp, config.h, firmware.ino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]
2026-08-21 Heartbeats on the main nav screen + channel noise-floor monitor with alert
    - Nav screen no-position branch: show 'Beacon HB Ns ago', rocket ID/CH/sats,
    no-fix uptime and RSSI/SNR instead of a bare 'No RF Data' - the operator
    can watch pad sat-acquisition live. With position data, row 1 appends
    'HB:Ns' when the heartbeat is fresher than the last position packet.
    - Noise monitor: GetRssiInst (0x15) sampled at 1 Hz while the chip is
    confirmed in RX; floor = 25th percentile of a 16-sample window so
    mid-packet samples can't inflate it. Alert at >= -100 dBm with 5 dB
    hysteresis; shown as 'RF NOISE! -xxdBm' on row 1 of the nav screen,
    'NF:-xxdBm' on the no-data nav screen and RF stats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
    [lora.c, lora.h, main.c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]
2026-08-21 8-channel 250 kHz band plan (433.00-434.75); decouple rocket ID from channel
    - Band split: 8 channels at 250 kHz spacing inside the 70cm auxiliary/link
    segment (433-435 MHz) - full Technician privileges, clear of the 432-433
    weak-signal/EME and 435-438 amateur-satellite segments, one full signal
    BW (125 kHz) of guard between adjacent channels, all inside one SX1268
    image-calibration band (no recal when hopping).
    - ID and channel are now independent: 'make flash ID=3 CHANNEL=5' sets
    -DROCKET_ID / -DLORA_CHANNEL separately (either alone works; ROCKET=n
    kept as shorthand for ID=n CHANNEL=n). Per-combo build dirs. Compile-time
    #error if LORA_CHANNEL is out of range.
    - Backup jumper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
    [lora.h, main.c, mpu_config.h]
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2026-08-21 Fix 60s boot deaf-spot: re-arm scan dwell at loop entry, show scan on nav
    SD logs from three boots told the real story: every run locked at ~61s
    (61.615, 68.277, 61.699) - one full 52s scan lap plus init - and always
    on CH0, the boot channel. Cause: StartScan arms the dwell timer ~5s into
    boot, but the init screens (test pattern 2s, RF/SD/self-test/beacon-
    restore/compass banners ~10s+) exhaust the boot channel's 6.5s dwell
    before the first ScanUpdate() ever runs, so the scan instantly hops off
    CH0 without listening and tours seven empty channels before returning.
    With TX and RX powered up together the beacon always starts talking
    during that wasted lap: 'RX doesn't register heartbeats at bo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
    [main.c]
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2026-08-22 Heartbeat now says WHY there's no fix: GPS health byte from the TX
    'sats: 0' on the receiver cannot distinguish a GPS that is still
    acquiring (wait) from a broken wire or dead module (get the rocket off
    the pad). The TX has known the difference all along - its GPS watchdog
    tracks UART-byte and NMEA-sentence liveness - but only printed it to
    its own USB serial, which nobody sees in the field.
    Transmitter:
    - gps.cpp: file-scope liveness timestamps (last UART byte, last
    recognizable GGA/RMC - recorded before validity checks, fix or not)
    and the watchdog reset counter; new gps_get_health() classifies:
    NO_DATA (UART silent >3s: wiring/power/module), NO_NMEA (bytes but
    nothing parses >5s: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
    [beacon.cpp, gps.cpp, main.c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]
2026-08-22 Latch heading validity once compass calibration is proven this session
    The nav screen's CAL indicator flapped: figure-8 the unit, CAL clears,
    set it down, CAL returns. heading_valid tracked the BNO055's live
    CALIB_STAT, but CALIB_STAT is a confidence score, not a validity flag:
    NDOF fusion decays mag_cal back to 0 when the device sits motionless,
    and worse, the auto-save that fires when mag_cal reaches 2 round-trips
    CONFIG<->NDOF (Compass_GetCalibrationData), which resets CALIB_STAT
    outright - so calibrating WELL caused a CAL relapse moments later. The
    offsets stay loaded and the heading stays good through all of this.
    Fix: once mag_cal >= 1 is observed, latch heading_valid for the rest of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
    [compass.c]
2026-08-22 Sync EVENT/ERROR log entries immediately - no-fix sessions lost everything
    Header-only L000N.TXT files (exactly 184 bytes = the CSV header) turned
    up on a field card, from sessions where the beacon was demonstrably
    heard: the log file is only created on proof of beacon (scan lock,
    heartbeat, callsign). Root cause: only SD_Card_LogNavigation ever called
    lfs_file_sync. A pad session with no GPS fix never logs a nav row, so
    the scan-lock and heartbeat events sat in the littlefs cache and
    power-off reverted the file to its last-synced state - the header.
    The record of when the scan locked and how sat acquisition progressed
    was destroyed in precisely the sessions where it mattered.
    Events are ra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
    [sd_card.c]
2026-08-22 RF init failure no longer bricks the session until a power cycle
    Field symptom: receiver boots, shows 'No signal' / Pkts:0 forever while
    the beacon transmits a metre away; a power cycle fixes it. Cause: a
    single failed RF_Receiver_Init() at boot showed 'RF Init Err' for 3
    seconds - easy to miss - then the unit ran the whole session with
    rf_initialized=0: no scan, no reception, and a 'No signal' display
    indistinguishable from 'beacon off'.
    - Boot: 3 init attempts with 250 ms settle between (same rationale as
    the SD mount retries).
    - Runtime: if still dead, retry init every 10 s; on recovery start the
    channel scan and log a durable ERROR line so the flaky radio bring-up
    is visible in th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
    [main.c]
2026-08-23 Resiliency review fixes + 100% line coverage on all tested modules
    Resiliency (RX):
    - RF_SPI_Init: three while(1) hangs replaced with RF_ERR_SPI_INIT /
    RF_ERR_DMA_TX_INIT / RF_ERR_DMA_RX_INIT error returns. A SPI/DMA init
    failure now shows a named code on the boot screen and enters the 10 s
    re-init retry loop instead of bricking with a blank display.
    - Local GPS init failure no longer blink-loops forever: the receiver's
    core job (hearing the beacon) does not need local GPS, so it warns for
    3 s and continues without distance/bearing.
    - IWDG armed (~32 s) before the main loop, fed each iteration: HardFault,
    Error_Handler and wedged bus transactions now cost a reset instead of a
    d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
    [firmware.ino, gps.cpp, main.c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]
2026-08-23 Review round 3: eliminate last two RX hang paths
    - display.c: I2C1 init failure ran while(1) - a broken OLED (or shorted
    I2C bus) bricked the whole receiver. Now sets display_i2c_failed and
    runs headless: RF reception, SD logging and the packet LED still work,
    and all display I2C traffic is skipped so a dead bus doesn't burn a
    25 ms HAL timeout per chunk in the main loop.
    - main.c: Error_Handler and HardFault_Handler spun forever; with the
    IWDG that meant a 32 s outage per fault. Both now NVIC_SystemReset()
    immediately - on a fault the state is corrupt and every second hung
    is beacon packets missed. IWDG remains the backstop.
    Audited and found sound (no changes needed): lora.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
    [display.c, main.c]
2026-08-23 Host tests for RX hardware-bound modules: button, display, gps, sd_card
    New test suites (fakes simulate the hardware surface; module sources are
    #included for static access):
    - test_button.c: EXTI+GPIO simulation - debounce time gate, release-bounce
    state guard, short-press (fires at release) vs long-press (fires while
    held), button 2 fire-on-press, stuck-button retrigger block.
    - test_display.c: capturing I2C fake - init sequence, framebuffer pixel/
    line/rect/circle/char correctness, right-edge text clipping, update
    chunking (6 cmds + 64x17-byte chunks), and the headless-mode regression
    (I2C init failure => zero bus traffic, receiver keeps running).
    - test_gps.c: UART fake driving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
    [gps.c, sd_card.c]
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2026-08-30 TX GPS: unlatch stale fixes, re-arm the field-dead watchdog
    Field data 2026-08-30 (L0009/L0011/L0013/L0014): four sessions with
    zero satellites and heartbeat-only downlink for up to 20 minutes;
    rst=0 the whole time - the GPS watchdog never fired.
    Root cause chain, now fixed:
    - current_coords.valid latched forever once any sentence carried
    lat/lon (a hot-start cached position qualifies), and the watchdog's
    no-fix timer refreshed off that latch. GGA fix_quality=0 and RMC
    status V now clear valid again.
    - The watchdog now keys on a fresh GOOD fix: quality>=1 AND sats>0
    AND bytes flowing. The byte-freshness clause keeps total UART
    silence from cancelling its own recovery one poll late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
    [gps.cpp]
2026-08-30 RX: 5 Hz tilt-robust compass, I2C self-recovery, clearer fault display
    Field feedback 2026-08-30: 1 Hz compass refresh was unusable while
    walking, and heading went sporadic when the receiver was tilted.
    Compass driver (compass.c):
    - Heading now comes from the BNO055 quaternion registers once a
    convention lock is established: 8 candidate earth-frame conventions
    are compared against the (low-tilt, calibrated) Euler heading and
    the matching one is locked. The quaternion path is immune to the
    Euler gimbal glitch region that makes headings jump when pitched.
    - Near-vertical device axis (heading geometrically undefined) sets a
    new orientation_valid=0 flag instead of emitting garbage.
    -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
    [compass.c, main.c]
2026-08-30 RX compass: keep pointing at stale headings, flagged as stale
    On comm loss with a previously-trustworthy heading, the driver now
    keeps the last value in Compass_Data and sets heading_stale instead of
    blanking the screen: the navigation arrow blinks at ~2 Hz (250 ms
    redraw cadence), compass screens mark the heading with '*', and the
    error splash only appears when the unit never calibrated this boot.
    Clears on the first healthy update. Tests: stale flag lifecycle +
    error-streak coverage updated; RX suite green (1252 checks), target
    ELF builds.
    [compass.c]
2026-08-30 RX: recover from mid-session radio wedges (chip falls out of RX)
    RF_EnsureRxMode entered RX exactly once ever, so a chip knocked out of
    RX mid-session (EMI, glitched SPI command, 3V3 sag) stayed deaf until
    power cycle while the display still showed the last lock. The 4 Hz
    diagnostic status read already knows the device mode - now a sustained
    3 s not-RX streak re-enters RX, escalating to a full LoRa_Init after
    3 failed retries. The channel scan is exempt (CAD parks the chip in
    standby between sniffs by design). Recoveries are counted and logged
    to the SD card as durable field evidence. Test: wedge injection,
    retry ladder, re-init escalation, quiet after restore. Suite green
    (1259 checks); tar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
    [main.c, rf_receiver.c, rf_receiver.h]
2026-08-30 Resiliency: bound TX mid-sentence GPS hang; RX IWDG armed at boot; cheap I2C scan
    TX (gps.cpp): the NMEA sentence reader had an infinite loop - if the
    UART went silent mid-sentence (GPS reset by the watchdog's new cold
    start, power blip, connector jiggle), the outer while() spun forever
    and the 16 s WDT rebooted the whole beacon. The declared-but-unused
    sentence_timeout now bounds the wait: ~50 ms of silence abandons the
    partial sentence and the next '$' resyncs. Regression test included
    (would hang the suite without the fix).
    RX (main.c): the IWDG was armed only AFTER all boot init, so a boot-
    time hang (wedged I2C bus scan, SD bring-up, stuck HAL init) bricked
    the ground station until a m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
    [compass.c, gps.cpp, main.c]
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2026-08-30 Field resiliency: GPS launch fallback, landing detect, display wedge recovery, auto re-scan, LOST marker, pre-flight page
    TX:
    - GPS-altitude launch fallback (launch_detect.cpp): sustained +50 m climb
    over 3 consecutive 1 Hz fixes confirms launch identically to the IMU
    path - a dead BNO085 no longer pins the beacon at pad cadence for the
    whole flight. Pad-drift and one-shot semantics covered by tests.
    - Landing detection: quiet linear accel AND stable altitude for 60 s
    (descent passes the accel half but never the altitude half) drops the
    beacon to BATTERY_SAVE cadence early - longer recovery window.
    RX:
    - display.c: runtime I2C wedge handling - 32 consecutive HAL errors go
    headle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
    [display.c, firmware.ino, launch_detect.cpp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]
2026-08-30 TX: radio wedge recovery - TX-failure streak forces full chip re-init
    transmit_packet() failures were logged and dropped, so a wedged SX1268
    (BUSY stuck, EMI/SPI glitch from the 33 dBm PA) left the beacon
    permanently silent while the 16 s WDT saw a healthy loop. Now 8
    consecutive failures force radio_init() (NRST pulse + begin(), the only
    reset the chip honours once wedged), and a dead chip retries a re-init
    every 8 transmit attempts so a transient radio brownout self-heals
    without a beacon reboot. Successful init re-arms the radio_enable()
    retry ladder (previously permanently exhausted after 3 tries).
    Host tests: streak triggers re-init, mid-streak success resets the
    counter, dead chip ret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
    [radio.cpp]
2026-08-30 Test coverage to ~100% on both targets
    TX firmware: 100% line coverage on all 8 modules (was 92-100%).
    - gps: framing-glitch bytes skipped both before '$' and mid-sentence
    - beacon: altitude sanity floor test; removed the unreachable negative
    clamp (validation already floors at -500 m, inside int16 range)
    - launch_detect: advisory rotation-vector enable failure warns but still
    initializes; get_time_since_launch() pre-launch returns 0
    - uart: flush_uart_buffer drains pending bytes
    RX firmware: 100% on 9 of 10 modules (was 89-100%).
    - display: runtime I2C error streak -> headless -> probe recovery cycle;
    SendData guards; removed the two Bresenham inner breaks after
    exhaustively verify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
    [beacon.cpp, display.c, gps.c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]
2026-08-30 Review fixes: compass error channel clobber + stale IWDG reset flag
    compass.c: routine 'Heading: ...' debug ran through Compass_SetError(0,...)
    on every healthy update (5 Hz), wiping any latched error message and
    resetting the code to 0x00 - the IMU self-test FAIL screen showed
    'Err: 0x00' and a heading instead of the actual fault. Routed to debug
    slot 4 with a regression test (healthy updates must preserve error state).
    main.c: RCC reset flags were only cleared on the SD-init-OK path, so an
    IWDGRSTF set on a boot where the card failed would survive into a later
    boot and log a spurious 'Boot after IWDG watchdog reset'. RMVF clear is
    now unconditional. Also fixed a stale '500 ms display thro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
    [compass.c, main.c]
2026-08-30 Protocol boundary review: fix dropped callsign packets in binary mode
    The callsign packet ("CALLSIGN-id CHn", no type byte, variable length)
    matched none of the binary dispatch branches (GPS=13B, FUSED=21B,
    heartbeat=7/8B), so it was silently discarded - main.c's callsign
    logging could never fire and the operator had no way to confirm which
    airframe/channel was locked. Route printable comma-free ASCII packets to
    RF_Parser_ParseAsciiPacket (which classifies them as callsigns) without
    marking position data ready, same policy as heartbeats. Regression test
    covers capture, non-position semantics, and binary-garbage rejection.
    Rest of the protocol boundary verified clean: modem params (SF9/BW125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
    [rf_receiver.c]
2026-08-30 RX GPS: GPS_IsFixed returns real parser fix state, not a stub
    GPS_IsFixed() returned a constant 1 ('for testing'). main.c ORs it into
    the local-GPS validity condition, so the validity of the operator's own
    position was decided by coordinate sanity alone: a module reporting its
    last-known position with fix=0 (many NMEA modules do exactly this on fix
    loss) would be accepted as a current fix. The parser already writes the
    real fix state from GGA quality / RMC A|V even on its no-fix error
    return, so latch it per sentence and return that. Tests updated to
    assert latch, clear-on-V, and re-latch behavior.
    [gps.c]
2026-08-30 EKF/nav review: add GPS innovation gate (multipath rejection)
    EKF math verified term-by-term (discretized white-noise-accel Q, Joseph
    form, axis decoupling) - correct. The gap: nav_update_from_gps folded
    every fix with quality>=1 and >=4 sats into the filter with no sanity
    check, so a 100 m multipath jump or a stale-position glitch corrupted
    the fused state; residuals were logged but never acted on.
    Add a normalized-innovation-squared gate: reject fixes with NIS > 16
    (~4 sigma, 3-dof chi-square 99.9%) AND >20 m from the filter estimate.
    Armed only while the IMU is healthy (predict tracks real dynamics, so a
    big innovation means the fix is wrong); fails open with a dead IMU
    (coasting filter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
    [config.h, nav.cpp]
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
